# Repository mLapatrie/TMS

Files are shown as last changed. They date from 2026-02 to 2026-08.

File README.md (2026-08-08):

# Low-Cost Transcranial Magnetic Stimulation

Graphical Abstract

Code, hardware, and data for the paper ["Low-Cost Transcranial Magnetic Stimulation"](TODO) (PREPRINT, SUBJECT TO CHANGES), (2026).

This repository contains the design and validation materials for a low-cost monophasic transcranial magnetic stimulation (TMS) stimulator. As of July 2027, the bill of materials (BOM) runs at USD 657.34. The repository includes the electrical design, controller firmware, and terminal control interface, fabrication files, LTspice simulations, raw magnetic-field measurements, and analysis code to characterize the system.

> [!CAUTION]
> This system contains a high-energy capacitor bank and generates high voltages and strong, rapidly changing magnetic fields. Contact with the system can cause severe injury or death, and stored energy can remain after charging is halted.
> Never rely on the computer interface or firmware as the primary safety mechanism. Work must be performed by trained personnel.
> Do not connect this research prototype to a person or animal.

## Cite
If you use this code, hardware, or data in your research, please cite the following paper:

> **Low-Cost Transcranial Magnetic Stimulation**
> Maxence Lapatrie, Yuzuha Isetani, Jathav Puvirajan, Antonella Catanzaro, Siqi Lyu, Han C. Nguyen, William   Mathieu, Milica Popovich.
> TODO

TODO BIBTEX

## Contact
I welcome any feedback on the paper or repository. If you have questions or require help running the code, please do not hesitate to contact me.

**Email me** at maxence (dot) lapatrie (at) mail (dot) mcgill (dot) ca.<br>
Or message me on **LinkedIn** [maxence-lapatrie](https://www.linkedin.com/in/maxence-lapatrie/).

## System overview
The design separates the build into three voltage domains: control domain, power domain, and high voltage domain. The domains are isolated from each other. The Arduino lives in the control domain and sends signals to the other two domains to control charging and discharging.

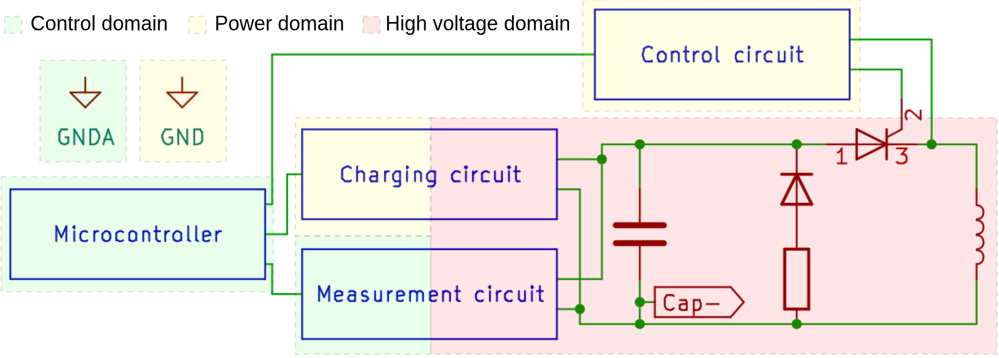
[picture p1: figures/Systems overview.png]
Systems Overview


See the complete [schematic](schematics/tms_schematic.pdf) for a more detailed understanding of the circuit.

## Repository contents
| Path | Contents |
| --- | --- |
| [`2d_models/`](2d_models/) | FreeCAD, SVG, PDF, and PNG fabrication drawings for the coil windings and busbars |
| [`3d_models/`](3d_models/) | FreeCAD sources and printable STL files for the coil winder and pickup coil helpers |
| [`controller_arduino/`](controller_arduino/) | Arduino UNO R4 Minima firmware and the Python terminal user interface |
| [`data_processing/`](data_processing/) | Raw oscilloscope captures, acquisition scripts, data analysis notebooks, SimNIBS helpers, and generated figures |
| [`figures/`](figures/) | Build, software-interface, and validation figures used in this README |
| [`schematics/`](schematics/) | KiCad project, hierarchical schematics, and a three-page PDF export |
| [`simulations/`](simulations/) | LTspice models for the charger, discharge path, gate driver, and IL300 linear optocoupler |
| [`Safety_Checklists.pdf`](Safety_Checklists.pdf) | Project-specific inspection, pre-charge, and de-energization checklists |
| [`TMS_field_grid.pdf`](TMS_field_grid.pdf) | Coordinate grids used for magnetic-field measurements |
| [`requirements.txt`](requirements.txt) | Pinned Python analysis environment |

Editable source files are included wherever possible. The PDF, SVG, STL, and PNG files are provided for convenience.

## Software setup

### Analysis environment

Python 3.10 or newer is recommended.
```bash
git clone <REPOSITORY_URL>
cd <REPOSITORY_DIRECTORY>

python3 -m venv .venv
source .venv/bin/activate
python -m pip install --upgrade pip
python -m pip install -r requirements.txt
```
Additional dependencies not included above:
- SimNIBS 4.6 is required by `data_processing/create_simple_figure_of_8_coil.py` and `data_processing/plot_simnibs.py`. Run these scripts in the Python environment supplied with the SimNIBS installation.
- KiCad, LTspice, and FreeCAD are recommended if one desires to edit the design files.

### Controller interface

Compile and upload [`controller_arduino.ino`](controller_arduino/controller_arduino.ino) to an Arduino UNO R4 Minima. Before compiling, review the pin assignments and calibrate the following firmware constants against the assembled measurement and gate-driver circuits:

- `MAX_ADC`: capacitor-bank overvoltage threshold in ADC counts;
- `FIRE_DELAY_US`: delay used to obtain the required SCR gate-pulse width;
- `COMP_STOP_ACTIVE`: active level of the independent comparator trip.

`MAX_ADC` must be calculated from measured values:

```text
MAX_ADC = round((V_trip / divider_ratio) / V_ref * ADC_FULL_SCALE)
```

The values committed in the firmware and terminal interface document the tested configuration; they are not universal safe defaults. The `DEFAULT_MAX_ADC` value in `app.py` must match the firmware `MAX_ADC`, and the divider ratio shown by the interface must match the physical divider tap in use.

```bash
cd controller_arduino
python app.py --divider <MEASURED_DIVIDER_RATIO> \
  --vref <MEASURED_ADC_REFERENCE_V> \
  --max-adc <FIRMWARE_MAX_ADC>
```

Press `p` in the interface to select a port.

| Key | Command |
| --- | --- |
| `r` | Reset the controller state after all hardware trips are clear |
| `c` | Start or stop charging |
| `a` | Arm or unarm the discharge; arming also stops charging |
| `f` | Request one firing pulse while armed |
| `s` | Query controller status |
| `p` | Select a serial port |
| `d` | Disconnect |
| `q` | Quit |

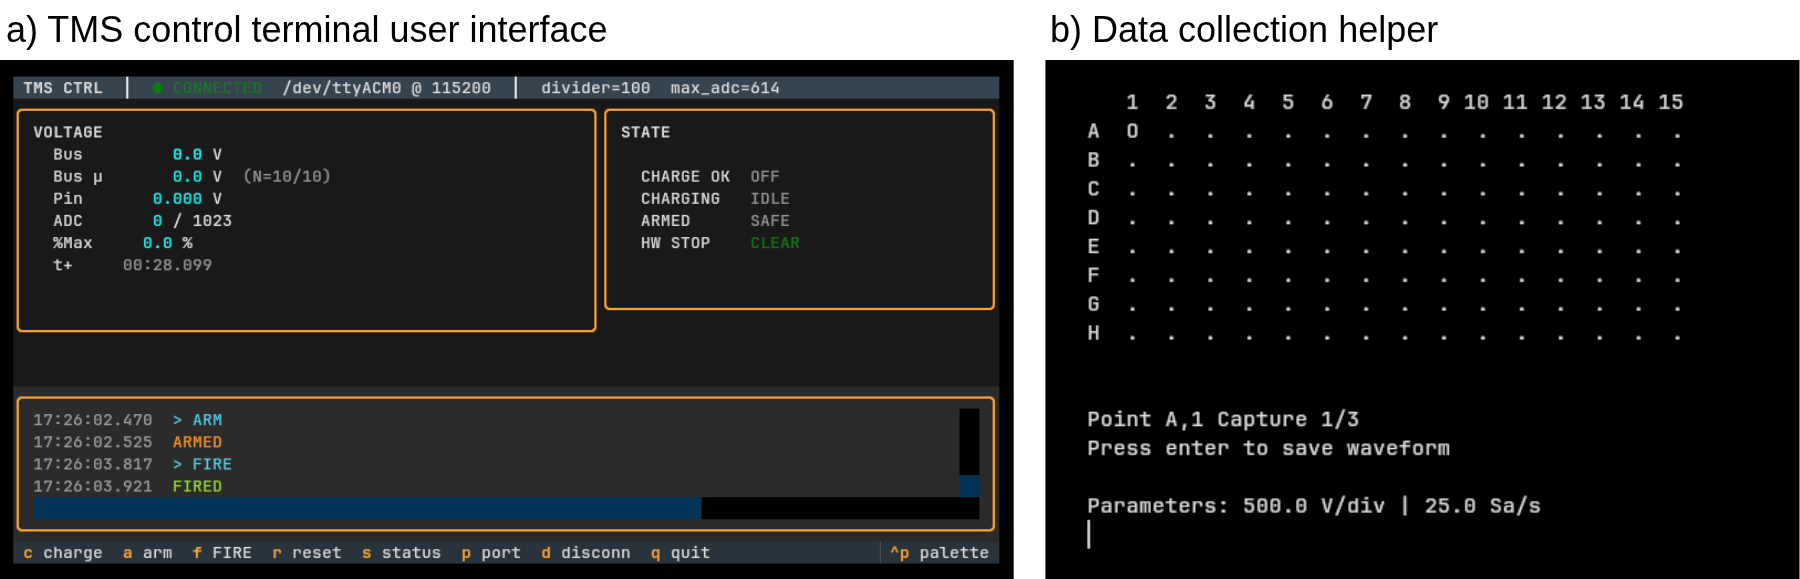
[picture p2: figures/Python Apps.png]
Controller interface and data-collection helper


## Data collection and analysis

The data used in our analyses is provided under [`data_processing/waveforms`](data_processing/waveforms). The MagVenture* components correspond to the data collected from the MRI-B91 MagVenture coil with the MagVenture MagPro X100 TMS. The other components correspond to the homemade coil under 24V and 1480V capacitor charges.

### Magnetic-field grid acquisition

[`collect_grid.py`](data_processing/collect_grid.py) automates oscilloscope captures at each location of a pre-programmed field-measurement grid. Before use:

1. Replace the VISA resource string with the identifier reported for the oscilloscope;
2. Select the measured field component;
3. Set `start_row` and `start_col` if resuming an interrupted acquisition; and
4. Confirm the oscilloscope channel, vertical scale, offset, sample rate, and binary-waveform format.

Each capture is stored as a CSV file with `Time (s)` and `Voltage (V)` columns.
Use [`TMS_field_grid.pdf`](TMS_field_grid.pdf) to help position your pickup coil.

### Deriving coil change of current

[`derive_didt.ipynb`](data_processing/derive_didt.ipynb):
1. Loads capacitor and three-axis pickup-coil waveforms;
2. Filters and maps the measured peak voltages;
3. Converts the measurements to empirical dB/dt maps;
4. Computes corresponding maps from a discretized figure-of-eight coil model; and
5. Estimates coil dI/dt by a global least-squares fit.

Change `user_local_dir` at the beginning of the notebook before running it. Select `homemade_coil` and `low_voltage` to match the dataset being analyzed.

### Other data analysis helpers

- [`plot_gate_pulses.ipynb`](data_processing/plot_gate_pulses.ipynb) compares the microcontroller and gate-resistor pulses and estimates the gate-current rise rate. It expects local files under `waveforms/gate_component/`.
- [`create_fo8_coil.py`](data_processing/create_fo8_coil.py) creates the line-segment TMS coil model used by SimNIBS.

## Example validation output

The repository includes raw low-voltage, high-voltage, and commercial-coil reference measurements. The figure below compares the measured and wire-segment-model dB/dt maps and shows the global least-squares fits used to estimate coil dI/dt at low and high capacitor-bank voltages:

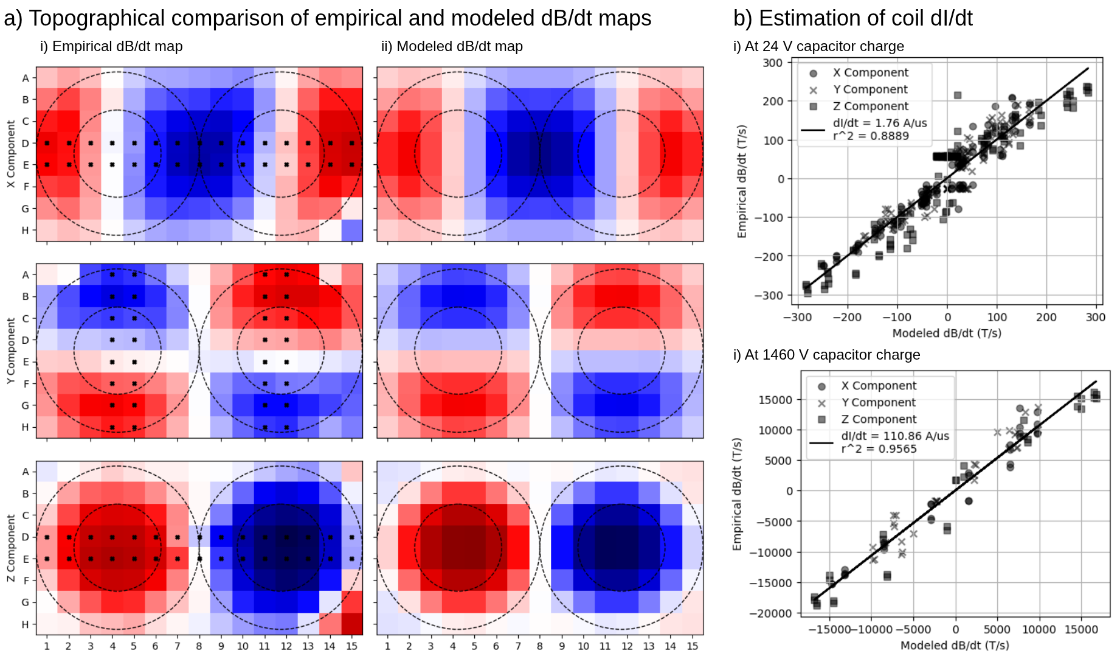
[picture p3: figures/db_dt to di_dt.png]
Empirical and modeled dB/dt maps with estimated coil dI/dt


## Safety documentation

Read [`Safety_Checklists.pdf`](Safety_Checklists.pdf) before inspecting or operating the physical system. These checklists document the procedures used for this prototype, but they are not a substitute for a complete, site-specific risk assessment or formal training.

## Licensing

The controller source files, data analysis code, and data collection code are licensed under the MIT SPDX license. The SimNIBS-derived coil-generation example retains its GPLv3 notice. All hardware files are licensed under the CERN-OHL-P-2.0 license. Project-authored data, figures, and documentation are licensed under the CC-BY-4.0 license. Read [LICENSE](LICENSE) for more information.

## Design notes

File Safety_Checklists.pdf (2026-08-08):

Safety Checklists

Device inspection

□ Bank voltage reads 0 V on the connected multimeter.

□ Busbars show no cracking along the flattened edges and have no loosened joints.

□ Nothing is touching the busbars except at the intended connection sites.

□ Bleeders and voltage divider resistors are visually intact and connected at their respective terminals.

□ Safety discharge stick is connected to the bank-negative busbar through discharge resistors and is within reach.

□ Correct transformer tap is selected for the target voltage.

□ Transformer taps are far away from each other.

□ Target voltage does not exceed the system’s maximum voltage.

□ Enclosure lid is closed; lid interlock closed.

□ Dead-man interlock is held by the second person.

□ Comparator trip threshold is set for the intended voltage.

□ Multimeter is readable and enclosed with the high voltage circuitry.

□ PSU current limit set according to expected maximum current draw.

□ TUI divider ratio matches the divider tap actually in use.

□ TUI shows a nominal state. Press R to reset if needed.

Pre-charge safety checklist

□ At least two people are present. Both have been briefed on the location and operation of the charge-cutoff switch, the discharge stick, and the de-energization checklist.

□ Operator is wearing Class 1 insulating rubber gloves and insulated footwear. Every person present is wearing impact-rated eye protection.

□ No rings, watches, or other conductive materials on either person.

□ Bench is clear of conductive clutter, tools, and stray wires.

□ No liquids on or near the setup.

□ A physical barrier separates the operator from the high-voltage components.

□ Both people are clear of the high-voltage region and ready for the circuit to be energized.

1

De-energization

□ Stop charging by pressing C again or pressing A to arm the system. The current draw should drop to quiescent levels.

□ Cut the PSU feed either by releasing the dead-man interlock or by pressing the charge-cutoff switch.

□ Turn the PSU off with its respective on/off switch, or by disconnecting the PSU directly from the wall.

□ Verify the multimeter is reading a non-zero voltage. Be wary of zero voltage readings as the multimeter might have been disconnected from the circuit or might be malfunctioning.

□ Allow the bleeders to drain the bank (leave untouched for at least 20 minutes), or

□ Make firm, quick contact with the safety discharge stick hook on the bank positive terminal through the enclosure port. Hold contact for at least 5 seconds.

□ Verify the multimeter reads a bank voltage of 0 V. Verify the multimeter probes are connected to the bank.

□ If the probes of the multimeter appear disconnected, connect the discharge stick for another 10 seconds and leave the device untouched for at least 20 minutes.

2

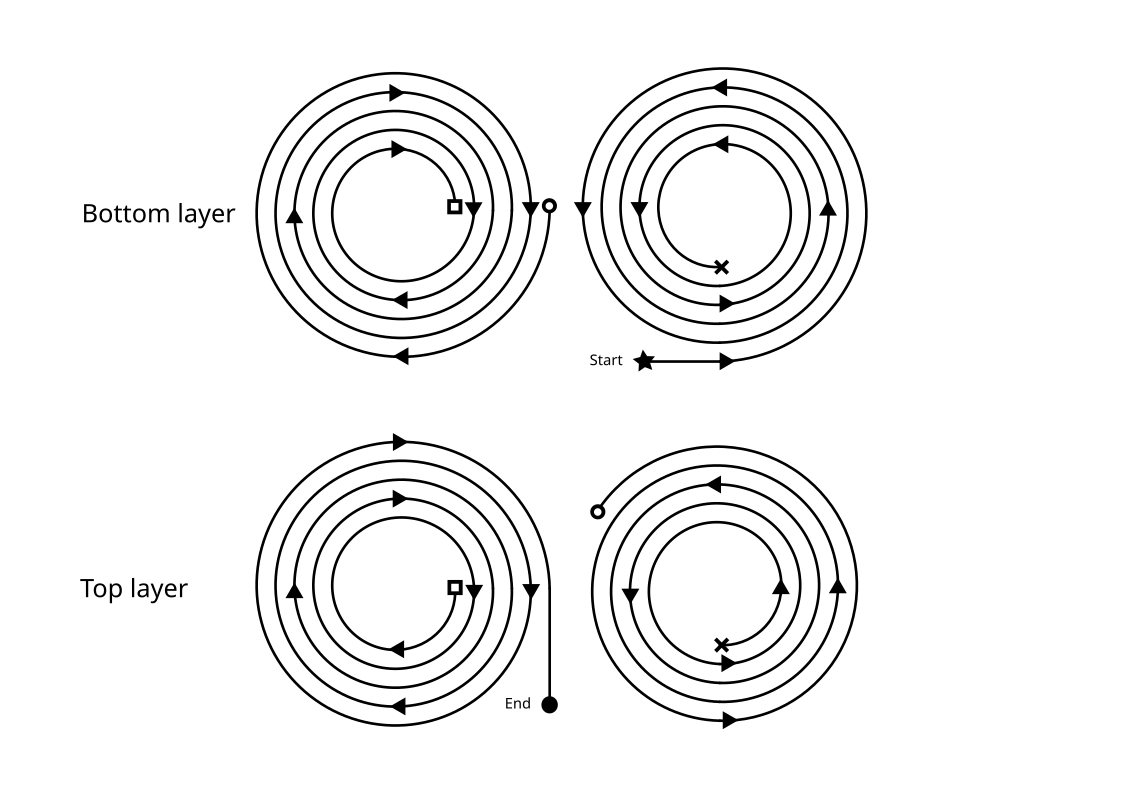
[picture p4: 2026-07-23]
2d_models/coil_windings/coil_windings.png

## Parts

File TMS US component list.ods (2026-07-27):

Designator | Component | Description | Qty | Cost Per Unit (USD) | Total Cost (USD) | Source of Materials | Material Type
Discharge Circuit: C1, C2 | C44UQGT6460T86K | Main discharge capacitors 460uF each | 2 | $110.56 | $221.12 | https://www.digikey.com/en/products/detail/kemet/C44UQGT6460T86K/18734476 | Metal
Discharge Circuit: R1, R2, R3, R4, R5, R6 | FMP200JT-52-220K | Bleed resistors 220k 2W | 6 | $0.20 | $1.20 | https://www.digikey.com/en/products/detail/yageo/FMP200JT-52-220K/9110366 | Metal
Discharge Circuit: D1,Q1 | MCMA260PD1800YB | SCR Module | 1 | $119.78 | $119.78 | https://www.digikey.com/en/products/detail/ixys/MCMA260PD1800YB/11304802 | Composite
Discharge Circuit: R7 | Dampening resistor | 1/8" (3MM) Wire Rope, 100FT Stainless Steel Cable | 1 | $16.99 | $16.99 | https://www.amazon.com/Antrader-Stainless-Crimping-Sleeves-Projects/dp/B0FQ4ZB6FR | Metal
Discharge Circuit | Busbar wiring | Copper Pipe Type M 3/4-inch x 5 Foot Straight Length | 1 | $26.81 | $26.81 | https://www.homedepot.com/p/Mueller-Streamline-3-4-in-x-5-ft-Copper-Type-M-Pipe-MH06005/100346419 | Metal
Discharge Circuit | Busbar isolation | Kapton tape | 1 | $2.50 | $2.50 | https://www.amazon.com/ELEGOO-Polyimide-Temperature-Resistant-Multi-Sized/dp/B072Z92QZ2 | Polymer
Discharge Circuit: R18 | 1MOhm 1/4W resistor | Voltage divider high side resistors | 10 | $0.10 | $1.00 | https://www.digikey.com/en/products/detail/stackpole-electronics-inc/CF14JT1M00/1741316 | Ceramic
Discharge Circuit: R19 | 22kOhm 1/4 resistor | Voltage divider low side resistor | 1 | $0.10 | $0.10 | https://www.digikey.com/en/products/detail/stackpole-electronics-inc/CFM14JT22K0/1742143 | Ceramic
Discharge Circuit: R19 | 3kOhm 1/4 resisotr | Voltage divider low side resistor | 1 | $0.10 | $0.10 | https://www.digikey.com/en/products/detail/stackpole-electronics-inc/CF14JT3K00/1741418 | Ceramic
Discharge Circuit: L1 | Coil wire | 10 AWG Stranded copper wire (25ft) | 1 | $14.99 | $14.99 | https://www.amazon.com/Translucent-Primary-Automotive-Lightning-Electrical/dp/B0CZ6QFZ67 | Metal
Discharge Circuit | Wire insulation | Kapton tape | 1 | $2.50 | $2.50 | https://www.amazon.com/ELEGOO-Polyimide-Temperature-Resistant-Multi-Sized/dp/B072Z92QZ2 | Polymer
Discharge Circuit | Coil insulation | Electric tape | 1 | $3.78 | $3.78 | https://www.amazon.com/Scotch-Electrical-Tape-4-Inch-66-Foot/dp/B001ULCB1O | Polymer
Discharge Circuit | Coil winder filament | 85g of PLA filament. 1kg for 20.39 cad. 1kg for 13.99 usd. | 1 | $1.19 | $1.19 | https://www.amazon.com/Printer-Filament-SUNLU-Dimensional-Accuracy/dp/B07XG3RM58 | Polymer
Discharge Circuit: SW1 | On/Off Switch | DC On/Off switch for PSU | 1 | $14.44 | $14.44 | https://www.digikey.com/en/products/detail/nkk-switches/JWMW21RC1A/2104374 | Composite
Discharge Circuit: SW2, SW3 | Contact switches (microwave door switches) | Interlock switches | 2 | $2.97 | $5.94 | https://www.amazon.com/Microwave-Switch-Interloc-Normally-Close/dp/B07XZFNPZM | Composite
Discharge Circuit: R8, R9 | 50W 1kOhm discharge resistor | Safety stick discharge resistors | 2 | $5.99 | $11.98 | https://www.digikey.com/en/products/detail/stackpole-electronics-inc/KAL50FB1K00/1646209 | Ceramic
Discharge Circuit | PVC pipe | PEX-B pipe for safety stick | 1 | $3.22 | $3.22 | https://www.homedepot.com/p/Apollo-1-2-in-x-5-ft-White-PEX-B-Pipe-APPW512/301541214 | Polymer
Discharge Circuit | 18 AWG HV silicone wire | Safety stick cable (5ft) | 5 | $1.41 | $7.05 | https://www.digikey.com/en/products/detail/cnc-tech/3239-18-1-0500-001-1-TS/3766986 | Polymer
Gate Driver Circuit: U12 | TC4420CPA | MOSFET gate driver | 1 | $2.02 | $2.02 | https://www.digikey.com/en/products/detail/microchip-technology/TC4420CPA/267369 | Composite
Gate Driver Circuit | A 08-LC-TT | 8 pin IC socket (optional) | 5 | $0.67 | $3.35 | https://www.digikey.com/en/products/detail/assmann-wsw-components/A-08-LC-TT/821740 | Composite
Gate Driver Circuit: C14 | 0.1 uF ceramic capacitor | Fast energy bank for the pulse | 1 | $0.24 | $0.24 | https://www.digikey.com/en/products/detail/tdk/FG18X7R1H104KNT06/5802879 | Ceramic
Gate Driver Circuit: C15 | 100 uF electrolytic capacitor | Slow energy bank for the pulse | 1 | $0.53 | $0.53 | https://www.digikey.com/en/products/detail/rubycon/50ZLJ100MT78X11-5/3134619 | Metal
Gate Driver Circuit: T2 | P0584NL | 1:1 Pulse Transformer | 1 | $4.77 | $4.77 | https://www.digikey.com/en/products/detail/pulse-electronics/P0584NL/2264931 | Composite
Gate Driver Circuit: D19, D20, D21, D22 | 1n5819 | Schottky Diodes | 4 | $0.29 | $1.16 | https://www.digikey.com/en/products/detail/diotec-semiconductor/1N5819/13164178 | Semiconductor
Gate Driver Circuit: R30 | 10 Ohm gate resistor | 10 Ohm gate resistor | 1 | $0.10 | $0.10 | https://www.digikey.com/en/products/detail/stackpole-electronics-inc/RNF14FTD10R0/1709720 | Ceramic
Gate Driver Circuit | 22 AWG wire | Wire for the whole circuit (1 m) | 1 | $0.30 | $0.30 | https://www.amazon.com/TUOFENG-Hookup-Wires-6-Different-Colored/dp/B07TX6BX47 | Metal
Gate Driver Circuit: U11 | VO2611 | HV Pulse Optocoupler | 1 | $2.25 | $2.25 | https://www.digikey.com/en/products/detail/vishay-semiconductor-opto-division/VO2611/1738647 | Composite
Gate Driver Circuit: R28 | 620 Ohm 1/4W resistor | 620 Ohm resistor for optocoupler LV side | 1 | $0.10 | $0.10 | https://www.digikey.com/en/products/detail/stackpole-electronics-inc/CF14JT620R/1741482 | Ceramic
Gate Driver Circuit: R29 | 1.2k Ohm 1/4W resistor | 1.2k Ohm resistor for optocoupler HV side | 1 | $0.10 | $0.10 | https://www.digikey.com/en/products/detail/stackpole-electronics-inc/CF14JT1K20/1741238 | Ceramic
Gate Driver Circuit: C13 | 0.1 uF optocoupler capacitor | 0.1 uF capacitor for optocoupler HV side | 1 | $0.24 | $0.24 | https://www.digikey.com/en/products/detail/tdk/FG18X7R1H104KNT06/5802879 | Ceramic
Charging Circuit: U1 | L7812CV | Linear voltage regulator | 1 | $1.17 | $1.17 | https://www.digikey.com/en/products/detail/stmicroelectronics/L7812CV/585973 | Composite
Charging Circuit: U2 | L7805CV | Linear voltage regulator | 1 | $1.05 | $1.05 | https://www.digikey.com/en/products/detail/stmicroelectronics/L7805CV/585964 | Composite
Charging Circuit: C5, C6 | 0.33 uF ceramic capacitor | Supports the voltage regulators | 2 | $0.32 | $0.64 | https://www.digikey.com/en/products/detail/tdk/FG24X7R1H334KNT06/5802993 | Ceramic
Charging Circuit: C7, C8 | 0.1 uF ceramic capacitor | Supports the voltage regulators | 2 | $0.24 | $0.48 | https://www.digikey.com/en/products/detail/tdk/FG18X7R1H104KNT06/5802879 | Ceramic
Charging Circuit: A1 | Arduino UNO R4 | Arduino | 1 | $20.00 | $20.00 | https://www.digikey.com/en/products/detail/arduino/ABX00080/20371542 | Composite
Charging Circuit: K1 | AZ9861-1C-24DC2R1 | 24 VDC relay | 1 | $5.66 | $5.66 | https://www.digikey.com/en/products/detail/american-zettler/AZ9861-1C-24DC2R1/18339576 | Composite
Charging Circuit: D2 | 1n5819 | Schottky Diode | 1 | $0.29 | $0.29 | https://www.digikey.com/en/products/detail/diotec-semiconductor/1N5819/13164178 | Semiconductor
Charging Circuit: C9 | 1189-1397-ND | 4700uF 50V capacitor | 1 | $3.50 | $3.50 | https://www.digikey.com/en/products/detail/rubycon/50PK4700MEFC18X40/3134353 | Metal
Charging Circuit: ZVS Driver | ZVS Driver | ZVS Driver | 1 | $15.99 | $15.99 | https://www.amazon.com/FainWan-Voltage-Inductor-Generator-DC12-30V/dp/B0BV6GYNK8 | Composite
Charging Circuit: T1 | ETD49/25/16-3C94 | Transformer Cores | 2 | $3.93 | $7.86 | https://www.digikey.com/en/products/detail/ferroxcube/ETD49-25-16-3C94/7041568 | Ceramic
Charging Circuit: T1 | B66368W1020T001 | Transformer Bobbin | 1 | $4.14 | $4.14 | https://www.digikey.com/en/products/detail/epcos-tdk-electronics/B66368W1020T001/3914849 | Polymer
Charging Circuit: T1 | B66368A2000X000 | Transformer Clips | 2 | $0.80 | $1.60 | https://www.digikey.com/en/products/detail/epcos-tdk-electronics/B66368A2000X000/3915618 | Metal
Charging Circuit: D3, D4, D5, D6, D7, D8, D9, D10, D11, D12, D13, D14, D15, D16, D17, D18 | UF4007 | HV Diode | 16 | $0.50 | $8.00 | https://www.digikey.com/en/products/detail/onsemi/UF4007/965478 | Semiconductor
Charging Circuit: R16, R17 | 1kOhm 25W | Resistor | 2 | $5.22 | $10.44 | https://www.digikey.com/en/products/detail/stackpole-electronics-inc/KAL25FB1K00/1646190 | Ceramic
Charging Circuit: U8A | LM393N/NOPB | Voltage Comparator | 1 | $0.92 | $0.92 | https://www.digikey.com/en/products/detail/texas-instruments/LM393N-NOPB/9526 | Composite
Charging Circuit: RV1 | 5kOhm potentiometer | Comparator voltage divider potentiometer | 1 | $5.35 | $5.35 | https://www.digikey.com/en/products/detail/cts-electrocomponents/026TB32R502B1A1/203779 | Composite
Charging Circuit: R23 | 5.6kOhm resistor | Comparator voltage divider resistor | 1 | $0.10 | $0.10 | https://www.digikey.com/en/products/detail/stackpole-electronics-inc/CFM14JT5K60/1742235 | Ceramic
Charging Circuit: R24 | 1MOhm resistor | Hysteresis resistor | 1 | $0.10 | $0.10 | https://www.digikey.com/en/products/detail/stackpole-electronics-inc/CF14JT1M00/1741316 | Ceramic
Charging Circuit: R25 | 10kOhm resistor | Comparator pull up resistor | 1 | $0.10 | $0.10 | https://www.digikey.com/en/products/detail/stackpole-electronics-inc/CF14JT10K0/1741265 | Ceramic
Charging Circuit: BT1 | 9V battery | Comparator battery | 1 | $1.59 | $1.59 | https://www.amazon.com/Amazon-Basics-Performance-All-Purpose-Batteries/dp/B00MH4QM1S | Metal
Charging Circuit: U3, U4, U9 | VO2611 | HV Pulse Optocoupler | 3 | $2.25 | $6.75 | https://www.digikey.com/en/products/detail/vishay-semiconductor-opto-division/VO2611/1738647 | Composite
Charging Circuit: R10, R13, R27 | 620 Ohm 1/4W resistor | 620 Ohm resistor for optocoupler LV side | 3 | $0.10 | $0.30 | https://www.digikey.com/en/products/detail/stackpole-electronics-inc/CF14JT620R/1741482 | Ceramic
Charging Circuit: R11 | 1.2k Ohm 1/4W resistor | 1.2k Ohm resistor for optocoupler HV side | 1 | $0.10 | $0.10 | https://www.digikey.com/en/products/detail/stackpole-electronics-inc/CF14JT1K20/1741238 | Ceramic
Charging Circuit: R26 | 1.2k Ohm 1/4W resistor | 1.2k Ohm resistor for optocoupler LV side | 1 | $0.10 | $0.10 | https://www.digikey.com/en/products/detail/stackpole-electronics-inc/CF14JT1K20/1741238 | Ceramic
Charging Circuit: C10, C12, C14 | 0.1 uF optocoupler capacitor | 0.1 uF capacitor for optocoupler HV side | 3 | $0.24 | $0.72 | https://www.digikey.com/en/products/detail/tdk/FG18X7R1H104KNT06/5802879 | Ceramic
Charging Circuit: C11, C13, C15 | 22 pF optocoupler capacitor | 22 pF capacitor for optocoupler HV side | 3 | $0.30 | $0.90 | https://www.digikey.com/en/products/detail/tdk/FA18NP01H220JNU06/5865955 | Ceramic
Charging Circuit: Q2, Q3 | BC337 NPN Transistor | NPN for relay coil control | 2 | $0.18 | $0.36 | https://www.digikey.com/en/products/detail/diotec-semiconductor/BC337-25/13164719 | Semiconductor
Charging Circuit: R12, R14 | 1.5kOhm 1/4W resistor | Base resistor for NPN | 2 | $0.10 | $0.20 | https://www.digikey.com/en/products/detail/yageo/CFR-25JB-52-1K5/132 | Ceramic
Charging Circuit: R3 | 10kOhm 1/4W resistor | Pull down NPN resistor | 1 | $0.10 | $0.10 | https://www.digikey.com/en/products/detail/stackpole-electronics-inc/CF14JT10K0/1741265 | Ceramic
Charging Circuit | 16 AWG wire | PSU to ZVS wiring | 1 | $3.33 | $3.33 | https://www.amazon.com/NAOEVO-Silicone-Electrical-Breadboard-Automotive/dp/B0CMLFRQDQ | Metal
Charging Circuit | 28 AWG enameled wire | Primary and secondary wiring (530 ft) | 1 | $11.99 | $11.99 | https://www.amazon.com/BNTECHGO-AWG-Magnet-Wire-Transformers/dp/B07DYF53ZN | Metal
Charging Circuit | 18 AWG HV silicone wire | Full bridge to capacitor wiring (1ft) | 1 | $1.41 | $1.41 | https://www.digikey.com/en/products/detail/cnc-tech/3239-18-1-0500-001-1-TS/3766986 | Polymer
Charging Circuit | 22 AWG wire | Wire for LV circuit boards (1 m) | 1 | $0.30 | $0.30 | https://www.amazon.com/TUOFENG-Hookup-Wires-6-Different-Colored/dp/B07TX6BX47 | Metal
Charging Circuit: U6 | IL300 | Linear Optocoupler | 1 | $3.81 | $3.81 | https://www.digikey.com/en/products/detail/vishay-semiconductor-opto-division/IL300/1731525 | Composite
Charging Circuit: U5, U7, U1 | UA741 | Op amp for linear optocoupler | 3 | $0.64 | $1.92 | https://www.digikey.com/en/products/detail/texas-instruments/UA741CP/382197 | Composite
Charging Circuit: R20, R22 | 100kOhm resistor | 100kOhm gain resistors for linear optocoupler | 2 | $0.10 | $0.20 | https://www.digikey.com/en/products/detail/stackpole-electronics-inc/CF14JT100K/1741263 | Ceramic
Charging Circuit: R21 | 1kOhm resistor | 1kOhm servo resistor | 1 | $0.10 | $0.10 | https://www.digikey.com/en/products/detail/stackpole-electronics-inc/CF14JT1K00/1741314 | Ceramic
Charging Circuit: U8A | LM358 | Op amp for voltage follower | 2 | $0.30 | $0.60 | https://www.digikey.com/en/products/detail/texas-instruments/LM358P/277042 | Composite
Charging Circuit | Dupont wires MM | Wires to arduino | 20 | $0.06 | $1.20 | https://www.amazon.com/Elegoo-EL-CP-004-Multicolored-Breadboard-arduino/dp/B01EV70C78 | Metal
Sensing | 28 AWG wire | Pick up coil (2ft), included in the transformer winding wire | 1 | $0.50 | $0.50 | https://www.amazon.com/BNTECHGO-AWG-Magnet-Wire-Transformers/dp/B07DYF53ZN | Metal
Sensing | PLA filament | PLA for winding cylinder (2g) | 1 | $0.05 | $0.05 | https://www.amazon.com/Printer-Filament-SUNLU-Dimensional-Accuracy/dp/B07XG3RM58 | Polymer
Sensing | 100x P4250 Probe | 100x oscilloscope probe with 2000Vpp rating | 1 | $22.99 | $22.99 | https://www.amazon.com/Goupchn-Voltage-Oscilloscope-Probe-P4250/dp/B086V9B67C | Composite
Sensing | PLA filament | PLA for sensing cross (6g) | 1 | $0.15 | $0.15 | https://www.amazon.com/Printer-Filament-SUNLU-Dimensional-Accuracy/dp/B07XG3RM58 | Polymer
Misc | Perforated boards |  | 6 | $0.25 | $1.50 | https://www.amazon.com/Rindion-Compatible-Prototype-Electronics-Soldering/dp/B0DBZ1BXFZ | Composite
Misc | M6 bolts |  | 2 | $2.97 | $5.94 | https://www.homedepot.com/p/M6-1-0x16mm-Stainless-Steel-Pan-Head-Phillips-Drive-Machine-Screw-1-Piece-863568/323368376 | Metal
Misc | M6 nuts |  | 2 | $3.97 | $7.94 | https://www.homedepot.com/p/Everbilt-M6-1-0-Zinc-Hex-Nut-5-Pieces-860728/323371196 | Metal
Misc | M6 washers | Large washers | 2 | $0.21 | $0.42 | https://www.homedepot.com/p/Everbilt-1-4-in-x-1-1-4-in-Zinc-Plated-Fender-Washer-804796/204632767 | Metal
Misc | Encasing | 50L container | 1 | $20.98 | $20.98 | https://www.homedepot.com/p/Sterilite-70-Qt-Ultra-Storage-Box-19888604/204606576 | Polymer
Misc | Zipties |  | 1 | $3.99 | $3.99 | https://www.amazon.com/Tensile-Strength-indoor-outdoor-Skalon/dp/B09PJ8L58G | Polymer
 |  |  |  | Total (USD, before tax) | $657.68

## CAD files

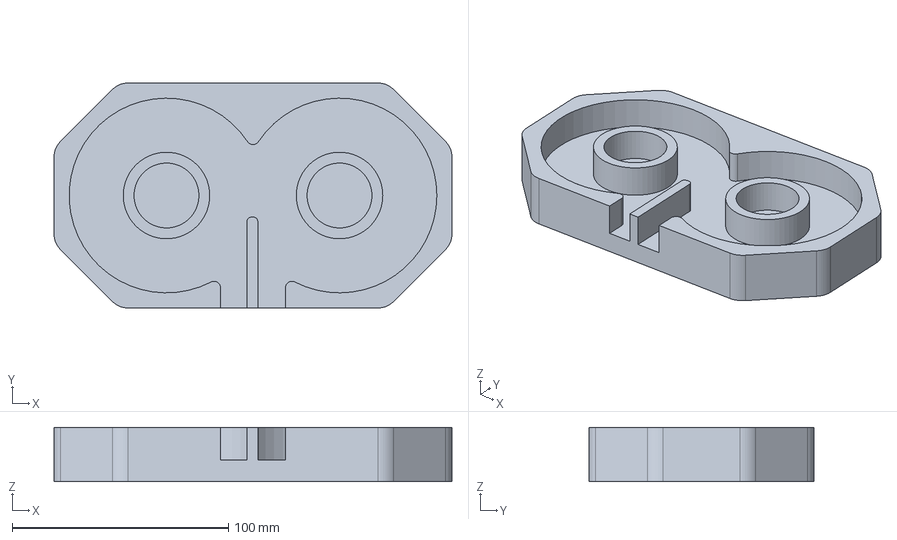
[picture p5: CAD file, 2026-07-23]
3d_models/coil_winder/coil_winder.FCStd
184.0 x 104.0 x 25.0 mm

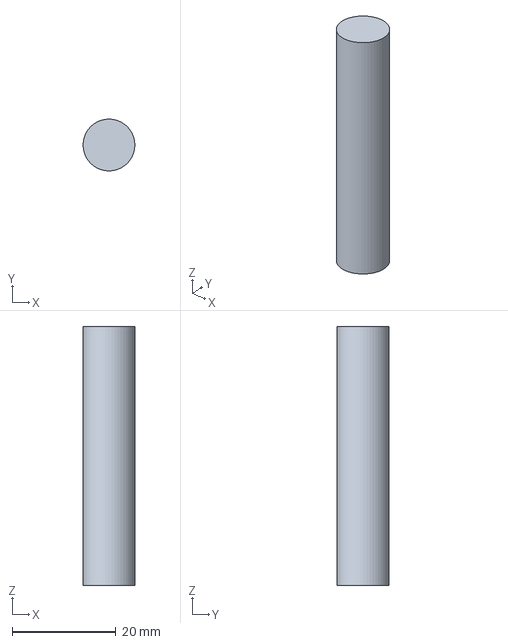
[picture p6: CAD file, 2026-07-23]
3d_models/pickup_cylinder/pickup_cylinder.FCStd
9.99 x 10.00 x 50.0 mm

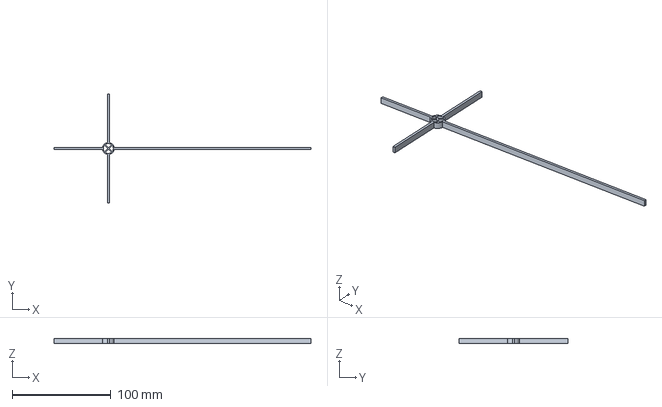
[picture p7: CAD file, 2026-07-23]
3d_models/sensing_cross/sensing_cross.FCStd
260.0 x 110.0 x 5.00 mm

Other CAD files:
2d_models/busbars/busbars.FCStd
2d_models/coil_windings/coil_windings.FCStd
3d_models/coil_winder/coil_winder.stl
3d_models/pickup_cylinder/pickup_cylinder.stl
3d_models/sensing_cross/sensing_cross.stl

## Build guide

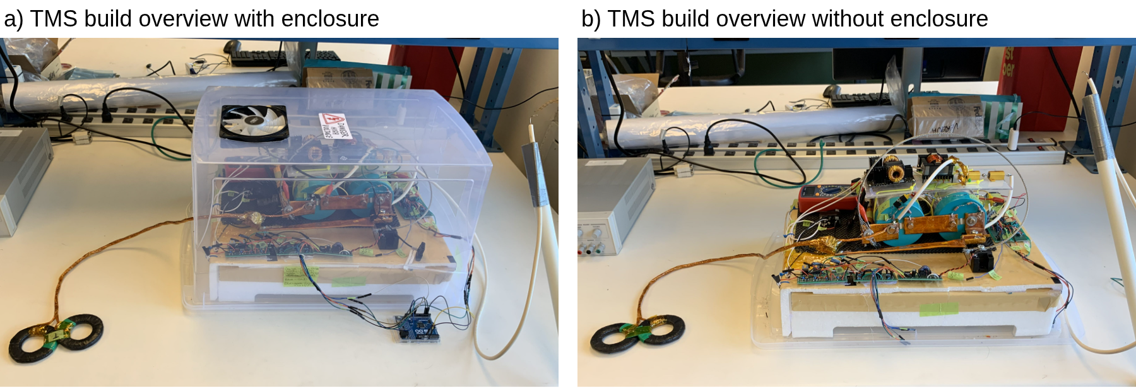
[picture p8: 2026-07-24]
figures/TMS build overview.png

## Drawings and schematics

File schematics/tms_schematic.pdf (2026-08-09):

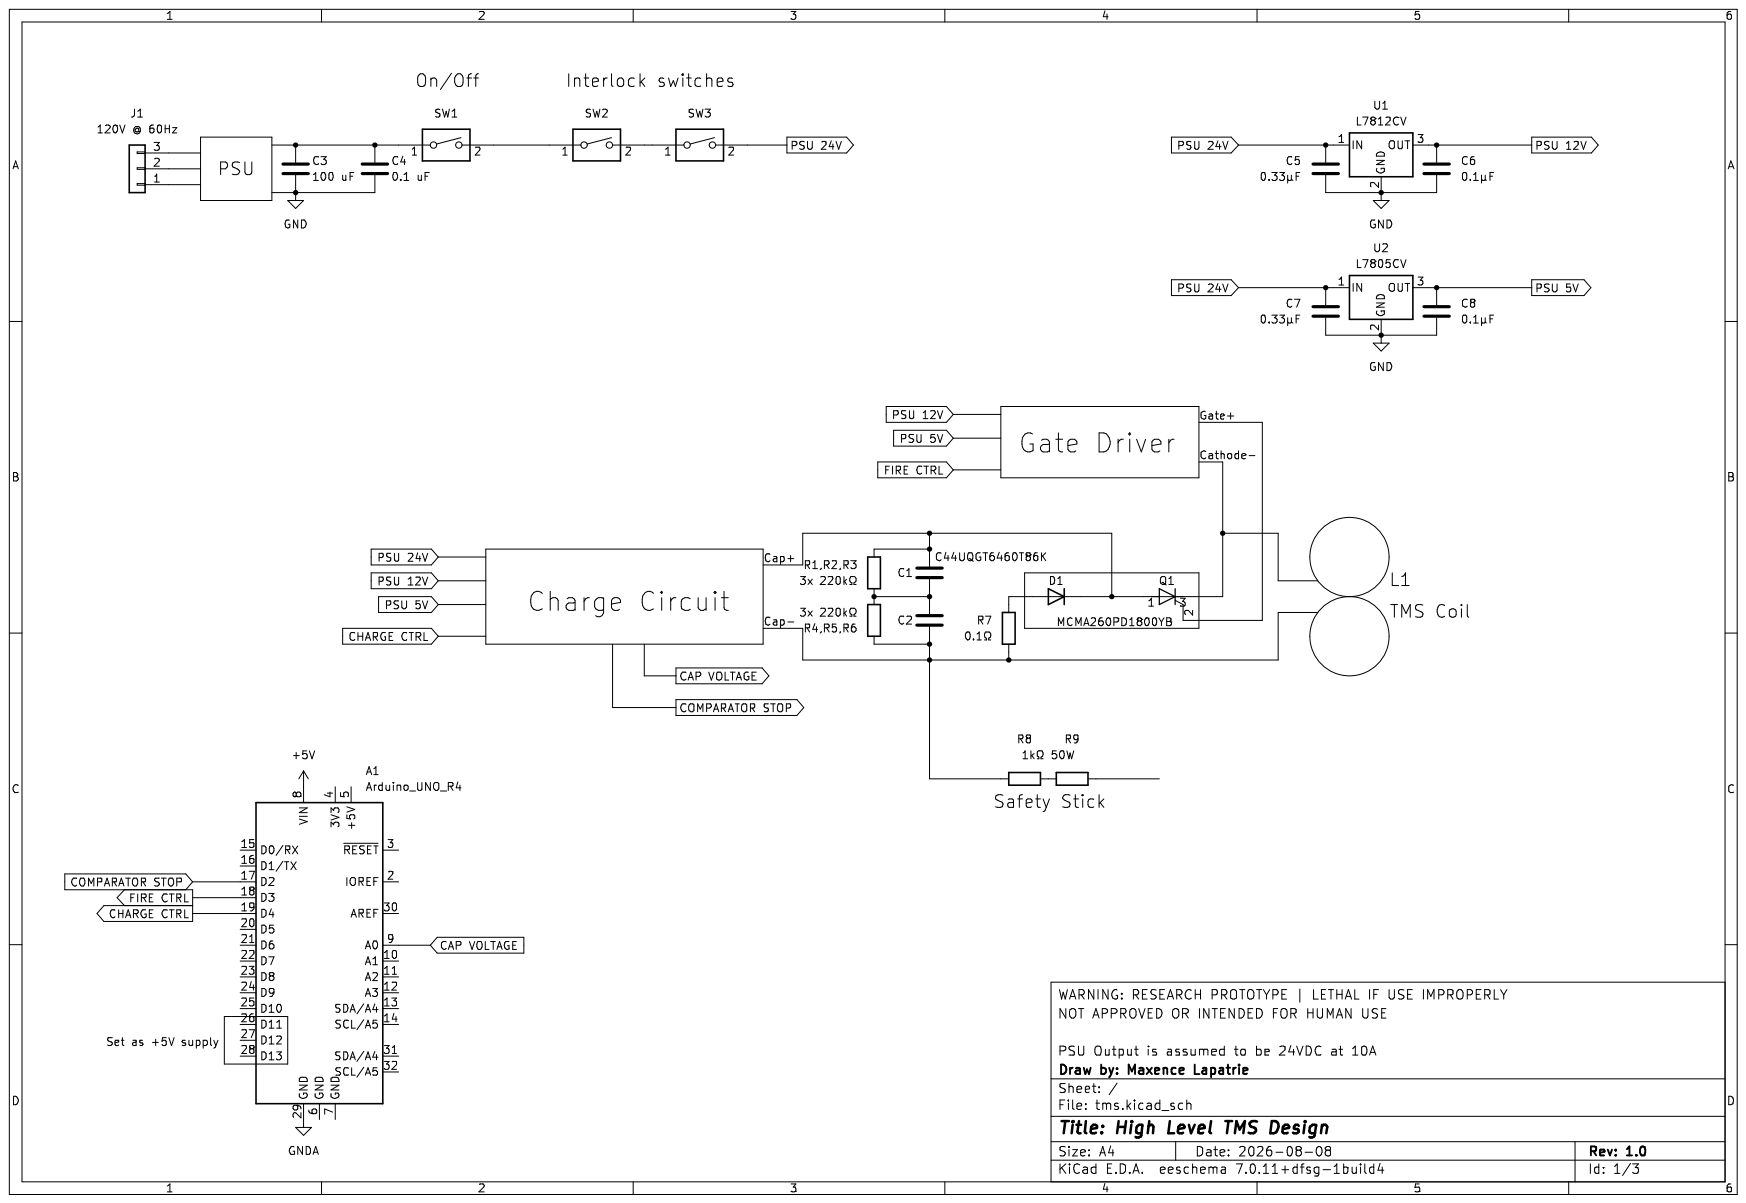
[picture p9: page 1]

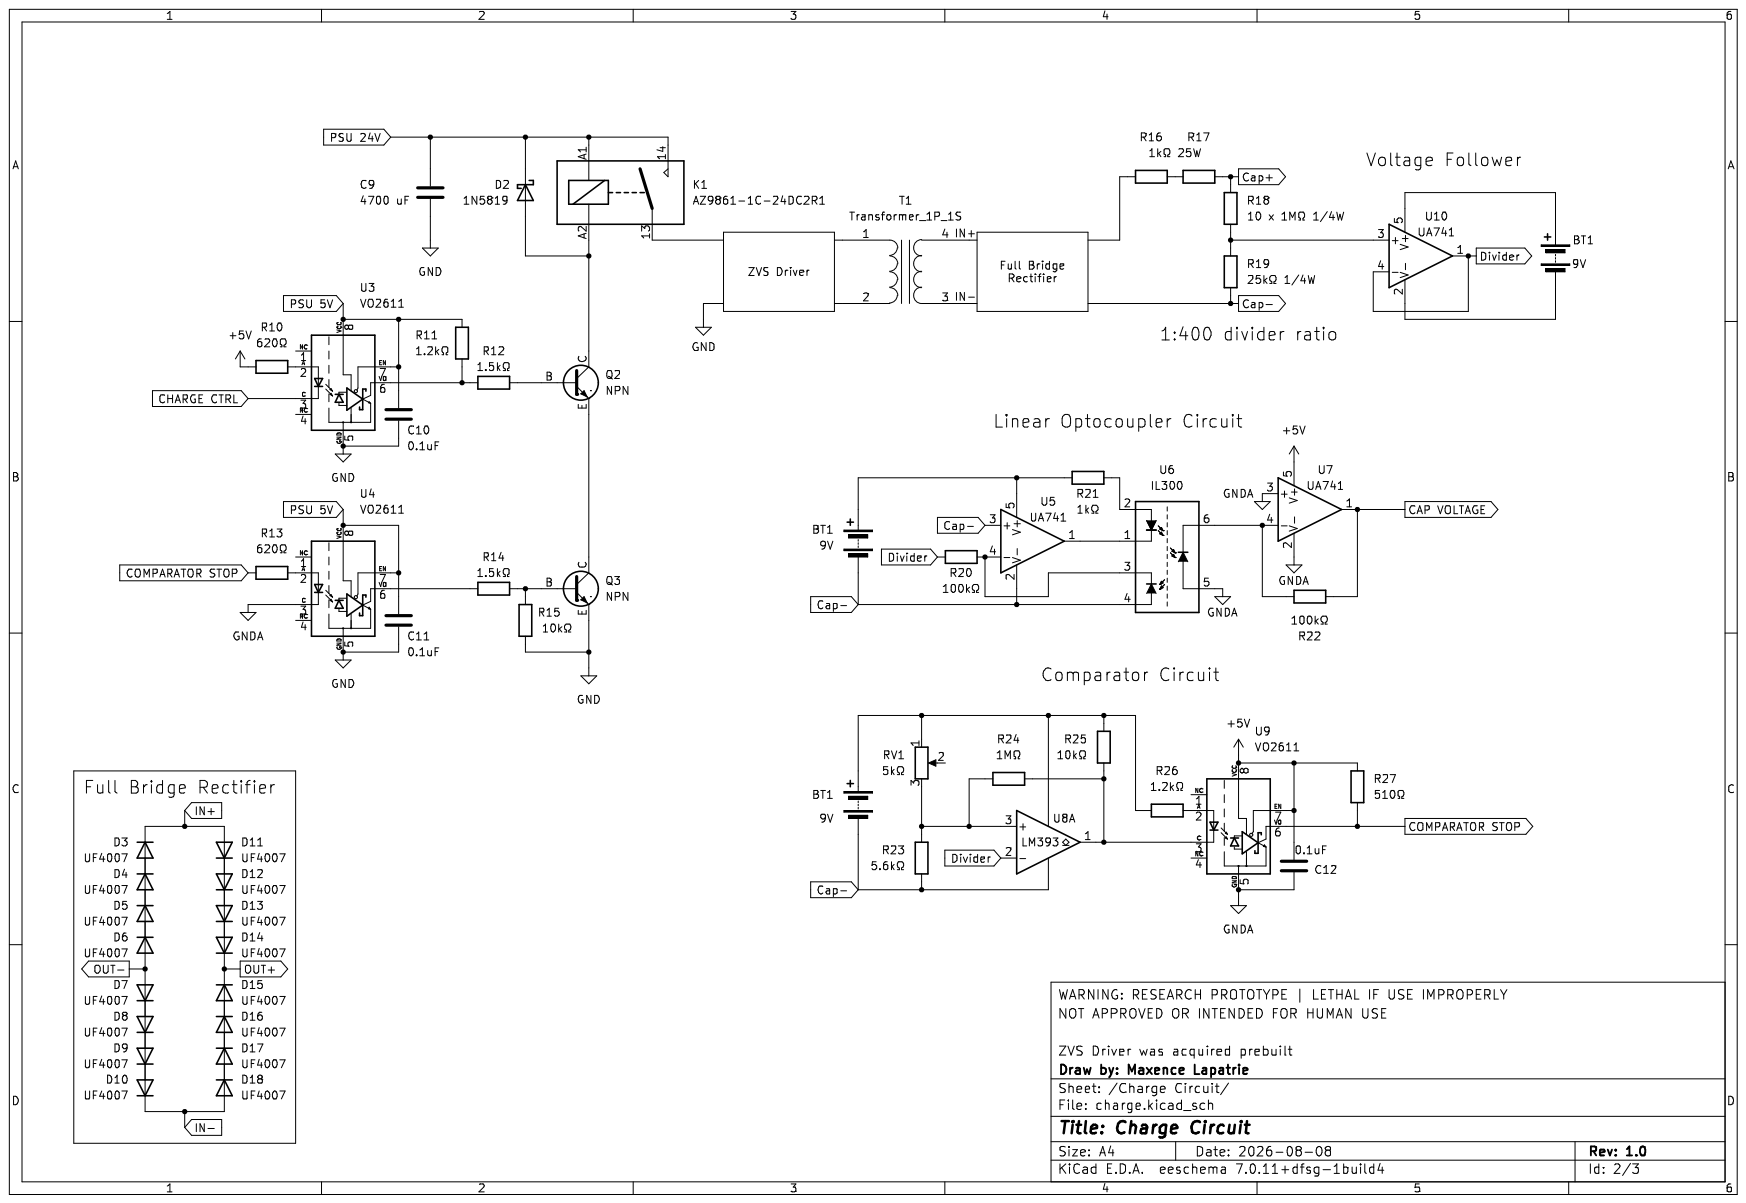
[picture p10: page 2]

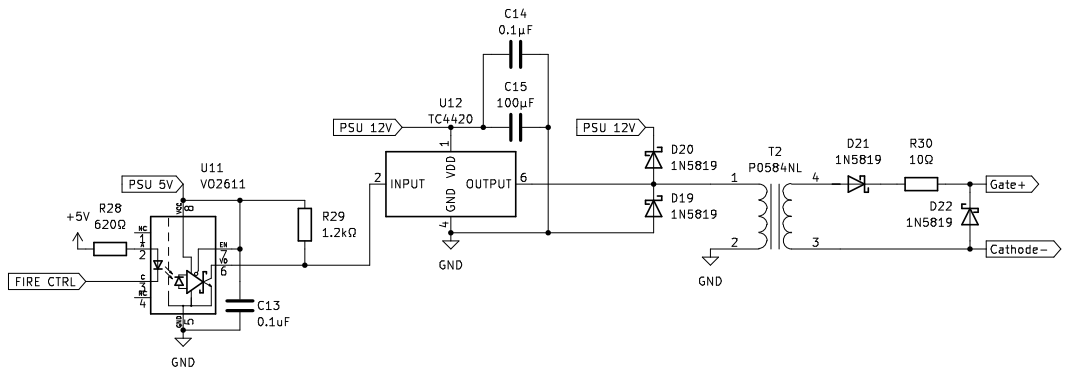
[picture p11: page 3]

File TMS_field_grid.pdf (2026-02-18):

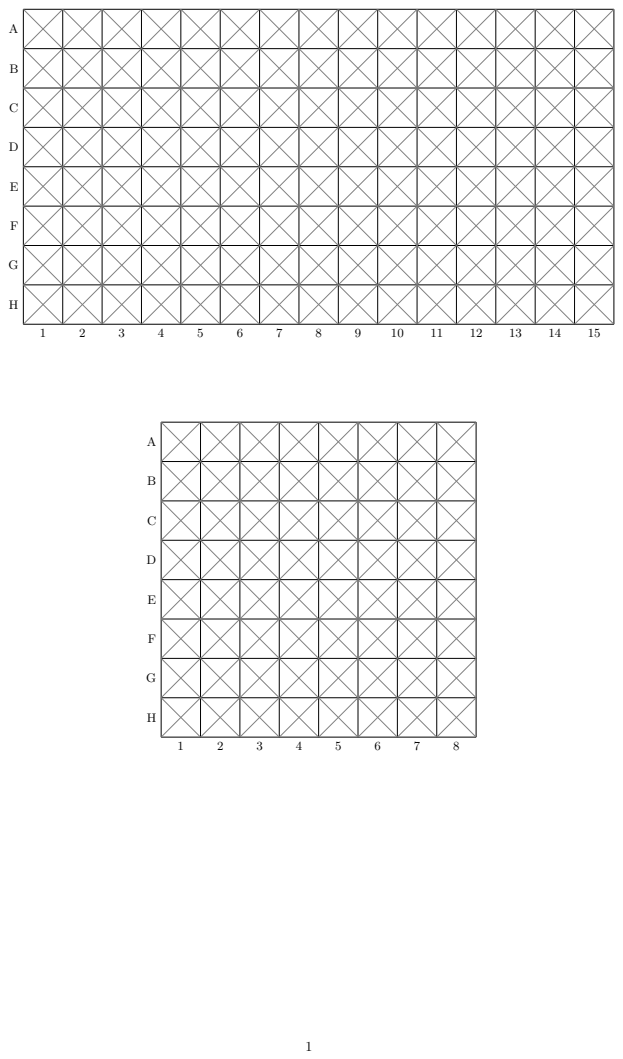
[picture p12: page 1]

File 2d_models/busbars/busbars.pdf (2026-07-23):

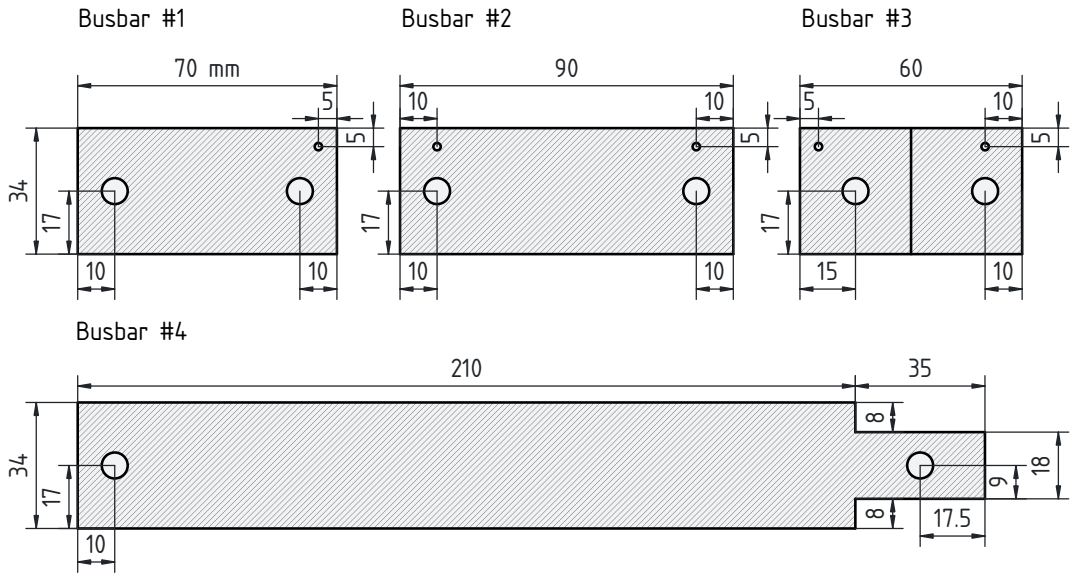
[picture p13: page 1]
Busbar #1; Busbar #2; Busbar #3; 10 10 Busbar #4

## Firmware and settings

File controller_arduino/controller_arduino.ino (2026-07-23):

// SPDX-License-Identifier: MIT
//
// TMS controller firmware for the Arduino UNO R4 Minima (Renesas RA4M1).
//
// This firmware controls high-voltage equipment. It is not a substitute for
// independent hardware interlocks, over-voltage protection, or safe operating
// procedures.

#include <Arduino.h>
#include <string.h>

// BEFORE STARTING -----------------------------------------------------------
// 1. Calculate MAX_ADC from measured values:
//
//       MAX_ADC = round((V_trip / divider_ratio) / V_ref * ADC_FULL_SCALE)
//
//    Example only: round(300 V / 100 / 5 V * 1023) = 614 counts.
// 2. Measure the SCR gate pulse on the assembled controller and adjust
//    FIRE_DELAY_US if the pulse width is not the required value.
// ---------------------------------------------------------------------------
static const uint8_t VCC_PINS[]      = {11, 12, 13};
static const uint8_t COMPARATOR_STOP = 2;
static const uint8_t FIRE_CTRL       = 3;
static const uint8_t CHARGE_CTRL     = 4;
static const uint8_t CAP_VOLTAGE     = A0;

// Comparator input configuration and active state
#define COMP_STOP_PIN_MODE INPUT
#define COMP_STOP_ACTIVE LOW

// ADC configuration. DEFAULT_MAX_ADC in app.py must match MAX_ADC.
static const uint8_t ADC_RESOLUTION_BITS = 10;
static const uint16_t ADC_FULL_SCALE = (1U << ADC_RESOLUTION_BITS) - 1U;
static const uint16_t MAX_ADC = 614;
static_assert(MAX_ADC <= ADC_FULL_SCALE,
              "MAX_ADC must be within the configured ADC range");

// Sampling and telemetry timing.
static const uint32_t SAMPLE_PERIOD_US = 1000;  // 1 kHz ADC sampling.
static const uint32_t TELEM_PERIOD_MS  = 100;   // 10 Hz host telemetry.

// Existing calibrated delay for an approximately 5 us SCR gate pulse.
// Re-measure on the final hardware; GPIO overhead depends on the board/core.
static const uint32_t FIRE_DELAY_US = 3;

// State shared with the comparator interrupt.
volatile bool comp_stop_tripped = false;

// Command-state flags. RESET is required before charging.
bool charge_ok = false;
bool armed = false;
bool charging = false;

uint16_t adc_last = 0;
uint32_t t_last_ms = 0;
uint32_t next_sample_us = 0;
uint32_t next_telem_ms = 0;

// Configure the three outputs that the existing hardware uses as logic-HIGH
// sources. Do not connect loads that exceed the board's GPIO ratings.
static void rails_up() {
  const size_t pin_count = sizeof(VCC_PINS) / sizeof(VCC_PINS[0]);
  for (size_t i = 0; i < pin_count; i++) {
    pinMode(VCC_PINS[i], OUTPUT);
    digitalWrite(VCC_PINS[i], HIGH);
  }
}

// Return command-controlled outputs and state flags to the inactive state.
static void safe_outputs() {
  digitalWrite(CHARGE_CTRL, LOW);
  digitalWrite(FIRE_CTRL, LOW);
  armed = false;
  charge_ok = false;
  charging = false;
}

static void fire_once() {
  // Prevent an interrupt from stretching the calibrated gate pulse.
  noInterrupts();
  digitalWrite(FIRE_CTRL, HIGH);
  delayMicroseconds(FIRE_DELAY_US);
  digitalWrite(FIRE_CTRL, LOW);
  interrupts();
}

static void comp_stop_isr() {
  // Disable charging immediately; loop() performs the non-ISR bookkeeping.
  digitalWrite(CHARGE_CTRL, LOW);
  comp_stop_tripped = true;
}

// Handle the newline-terminated ASCII command protocol used by app.py.
static void handle_command(const char *cmd) {
  if (strcmp(cmd, "RESET") == 0) {
    safe_outputs();
    if (digitalRead(COMPARATOR_STOP) != COMP_STOP_ACTIVE) {
      comp_stop_tripped = false;
      charge_ok = true;
      Serial.println("RESET_OK");
    } else {
      Serial.println("RESET_BLOCKED_HW_TRIP");
    }
  }
  else if (strcmp(cmd, "CHARGE") == 0) {
    if (charge_ok && !armed && !comp_stop_tripped) {
      digitalWrite(CHARGE_CTRL, HIGH);
      charging = true;
      Serial.println("CHARGING");
    } else {
      Serial.println("CHARGE_DENIED");
    }
  }
  else if (strcmp(cmd, "UNCHARGE") == 0) {
    digitalWrite(CHARGE_CTRL, LOW);
    charging = false;
    Serial.println("UNCHARGED");
  }
  else if (strcmp(cmd, "ARM") == 0) {
    digitalWrite(CHARGE_CTRL, LOW);
    charging = false;
    charge_ok = false;
    armed = true;
    Serial.println("ARMED");
  }
  else if (strcmp(cmd, "UNARM") == 0) {
    armed = false;
    Serial.println("UNARMED");
  }
  else if (strcmp(cmd, "FIRE") == 0) {
    if (armed && !charge_ok && !comp_stop_tripped) {
      fire_once();
      armed = false;
      Serial.println("FIRED");
    } else {
      Serial.println("FIRE_DENIED");
    }
  }
  else if (strcmp(cmd, "STATUS") == 0) {
    char buf[96];
    snprintf(buf, sizeof(buf),
             "STATUS ok=%d arm=%d chg=%d hw=%d adc=%u",
             charge_ok, armed, charging, comp_stop_tripped,
             static_cast<unsigned int>(adc_last));
    Serial.println(buf);
  }
  else {
    Serial.print("UNKNOWN:");
    Serial.println(cmd);
  }
}

void setup() {
  pinMode(CHARGE_CTRL, OUTPUT);
  pinMode(FIRE_CTRL, OUTPUT);
  pinMode(COMPARATOR_STOP, COMP_STOP_PIN_MODE);
  pinMode(CAP_VOLTAGE, INPUT);
  analogReadResolution(ADC_RESOLUTION_BITS);

  safe_outputs();
  rails_up();

  // Latch a comparator trip that is already active at startup.
  if (digitalRead(COMPARATOR_STOP) == COMP_STOP_ACTIVE) {
    comp_stop_tripped = true;
  }

  attachInterrupt(digitalPinToInterrupt(COMPARATOR_STOP),
                  comp_stop_isr,
                  COMP_STOP_ACTIVE == HIGH ? RISING : FALLING);

  Serial.begin(115200);
  // Do not wait for a host connection; the controller may run from bench power.
  Serial.println("BOOT");
}

void loop() {
  const uint32_t now_us = micros();
  const uint32_t now_ms = millis();

  // Sample the capacitor-voltage monitor at approximately 1 kHz.
  if ((int32_t)(now_us - next_sample_us) >= 0) {
    next_sample_us = now_us + SAMPLE_PERIOD_US;
    adc_last = analogRead(CAP_VOLTAGE);
    t_last_ms = now_ms;

    if (adc_last > MAX_ADC) {
      digitalWrite(CHARGE_CTRL, LOW);
      if (charge_ok || charging) {
        charge_ok = false;
        charging = false;
        Serial.println("OVERVOLT");
      }
    }
  }

  // Complete handling of a hardware comparator trip latched by the ISR.
  if (comp_stop_tripped) {
    if (charge_ok || charging) {
      digitalWrite(CHARGE_CTRL, LOW);
      charge_ok = false;
      charging = false;
      Serial.println("HW_STOP_TRIPPED");
    }
  }

  // Report controller state to the host at approximately 10 Hz.
  if ((int32_t)(now_ms - next_telem_ms) >= 0) {
    next_telem_ms = now_ms + TELEM_PERIOD_MS;
    char buf[96];
    snprintf(buf, sizeof(buf),
             "T t=%lu adc=%u ok=%d arm=%d chg=%d hw=%d",
             static_cast<unsigned long>(t_last_ms),
             static_cast<unsigned int>(adc_last),
             charge_ok, armed, charging, comp_stop_tripped);
    Serial.println(buf);
  }

  // Read one newline-terminated command. Commands are at most 15 characters.
  if (Serial.available()) {
    static char cmd[16];
    size_t n = Serial.readBytesUntil('\n', cmd, sizeof(cmd) - 1);
    cmd[n] = '\0';
    while (n > 0 && (cmd[n-1] == '\r' || cmd[n-1] == ' ')) cmd[--n] = '\0';
    if (n > 0) handle_command(cmd);
  }
}

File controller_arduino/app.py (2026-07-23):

#!/usr/bin/env python3
# SPDX-License-Identifier: MIT
"""
tms_tui.py - Terminal UI for the TMS controller.

Dependencies:
    pip install "textual>=0.60" pyserial

Run:
    python app.py                    # pick port interactively
    python app.py --port /dev/ttyACM0
    python app.py --port COM3 --divider 100 --max-adc 614
    python app.py --list             # list available serial ports and exit

Keybindings (see footer):
    c   charge / uncharge       a   arm / unarm
    f   FIRE                    r   reset
    s   status query            p   pick port
    d   disconnect              q   quit

Platform notes:
    - Linux/macOS: works in any modern terminal.
    - Windows: works in Windows Terminal, PowerShell, and the newer
      Command Prompt. Use the Cascadia Mono or similar font for block
      characters in the sparkline. WSL is not required.
"""

from __future__ import annotations

import argparse
import queue
import sys
import threading
from collections import deque
from datetime import datetime

import serial
import serial.tools.list_ports

from textual.app import App, ComposeResult
from textual.binding import Binding
from textual.containers import Horizontal, Vertical
from textual.screen import ModalScreen, Screen
from textual.widgets import Footer, Label, ListItem, ListView, RichLog, Static

BAUD = 115200
ADC_FULL_SCALE = 1023
DEFAULT_DIVIDER_RATIO = 100.0
DEFAULT_ADC_REFERENCE_V = 5.0
DEFAULT_MAX_ADC = 614 # must maatch MSAX_ADC in firmware

# Display settings
DEFAULT_AVG_WINDOW = 10
SPARK_BLOCKS = " ▁▂▃▄▅▆▇█"
SPARK_WIDTH = 32
HISTORY_LEN = 100  # 10 s at 10 Hz telemetry


# ======================================================================
# Serial bridge (background read thread, main-thread writes)
# ======================================================================

class SerialBridge:
    def __init__(self) -> None:
        self.ser: serial.Serial | None = None
        self.rx_queue: queue.Queue[str] = queue.Queue()
        self._thread: threading.Thread | None = None
        self._stop = threading.Event()

    def is_open(self) -> bool:
        return self.ser is not None and self.ser.is_open

    def open(self, port_name: str) -> None:
        if self.is_open():
            self.close()
        # Default pyserial config. No DTR/RTS toggling.
        # R4 Minima uses native USB CDC so opening does not reset the MCU.
        self.ser = serial.Serial(port_name, BAUD, timeout=0.1)
        self._stop.clear()
        self._thread = threading.Thread(target=self._read_loop, daemon=True)
        self._thread.start()

    def close(self) -> None:
        self._stop.set()
        t = self._thread
        self._thread = None
        if t and t.is_alive():
            t.join(timeout=0.5)
        if self.ser:
            try:
                self.ser.close()
            except Exception:
                pass
            self.ser = None

    def send(self, cmd: str) -> None:
        if not self.is_open():
            return
        try:
            self.ser.write((cmd + "\n").encode("ascii"))
        except Exception as e:
            self.rx_queue.put(f"__WRITE_ERROR__:{e}")

    def _read_loop(self) -> None:
        buf = ""
        while not self._stop.is_set():
            try:
                data = self.ser.read(256) if self.ser else b""
            except Exception as e:
                self.rx_queue.put(f"__READ_ERROR__:{e}")
                return
            if not data:
                continue
            buf += data.decode("ascii", errors="replace")
            while True:
                nl = buf.find("\n")
                if nl < 0:
                    break
                line = buf[:nl].rstrip("\r")
                buf = buf[nl + 1:]
                if line:
                    self.rx_queue.put(line)


# ======================================================================
# Helpers
# ======================================================================

def parse_kv(s: str) -> dict[str, str]:
    out: dict[str, str] = {}
    for tok in s.split():
        if "=" in tok:
            k, v = tok.split("=", 1)
            out[k] = v
    return out


def sparkline(values: list[int], width: int, vmax: int) -> str:
    if width <= 0:
        return ""
    if not values or vmax <= 0:
        return " " * width
    n = len(values)
    if n >= width:
        step = n / width
        chunks = [values[int(i * step):int((i + 1) * step)] for i in range(width)]
    else:
        chunks = [[] for _ in range(width - n)] + [[v] for v in values]
    out = []
    top = len(SPARK_BLOCKS) - 1
    for c in chunks:
        if not c:
            out.append(" ")
            continue
        avg = sum(c) / len(c)
        ratio = min(1.0, avg / vmax)
        out.append(SPARK_BLOCKS[int(ratio * top)])
    return "".join(out)


def ts() -> str:
    now = datetime.now()
    return now.strftime("%H:%M:%S.") + f"{now.microsecond // 1000:03d}"


# ======================================================================
# Port picker
# ======================================================================
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

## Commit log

2025-12-26 Moved charge
2025-12-26 Moved discharge
    [discharge.sch]
2025-12-27 Discharge and RLC circuit helpers
2026-01-13 Added gate driver
2026-01-13 gate driver
2026-01-17 Added kicad files
    [charge.kicad_sch, discharge.kicad_sch, gate_driver.kicad_sch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]
2026-01-21 Kicad files
    [charge.kicad_sch, gate_driver.kicad_sch, tms.kicad_sch]
2026-01-21 Removed data files
    [discharge.sch]
2026-01-24 Schematic fixes after real life tests
    [charge.kicad_sch, gate_driver.kicad_sch, tms.kicad_sch]
2026-01-28 Linear Optocoupler schematic (non function rn)
2026-01-28 Cleaned schematic and fixed LV wiring
2026-01-29 Fixed optocoupler output logic
    [charge.kicad_sch, gate_driver.kicad_sch]
2026-01-29 Fixed the linear optocoupler schematic
    [charge.kicad_sch]
2026-01-30 Fixed TMS schematic
    [charge.kicad_sch, gate_driver.kicad_sch, tms.kicad_sch]
2026-02-03 controller arduino code added
2026-02-03 Update README with Arduino controller information
    Added section for Arduino controller code and its functions.
2026-02-05 Coil winder 3d files
    [coil_winder(Neurotech).iges, coilwinder2.obj]
2026-02-05 Added stripped winder
    [coil_winder.iges, coil_winder.obj, stripped_winder.obj]
2026-02-05 Removed duplicate
    [coilwinder2.obj]
2026-02-06 Updated schematic pdf
2026-02-19 Modified visualization code
    [20260217_TMS_Efield_VoltagePulse.xlsx, SDS00001.CSV, SDS00002.CSV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]
2026-03-02 Data collection script and db/dt heatmap
2026-04-19 Adding freecad
    [TMS_holder-Body.stl, TMS_holder.FCStd, sensing_cross-Body.stl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]
2026-04-22 Schematic changes
    [charge.kicad_sch, gate_driver.kicad_sch, tms.kicad_sch]
2026-05-11 Added auto arm after capture
2026-05-17 Organizational changes
    [TMS_holder-Body.stl, TMS_holder.FCStd, charge.kicad_sch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]
2026-05-25 Fixed optocoupler wiring bug
    [charge.kicad_sch, gate_driver.kicad_sch]
2026-06-12 Small changes
    [sensing_guide-Body.stl, sensing_guide.FCStd, sensing_pick-Body.stl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]
2026-06-14 Pickup cylinder
    [pickup_cylinder.stl, pickup_cylinder.stl.FCStd, pickup_winding_cylinder.stl]
2026-07-23 FreeCAD files for winding instructions and busbar dimensions.
    [busbars.FCStd, coil_windings.FCStd]
2026-07-23 Fixed 3d models and redid coil winder
    [coil_winder.FCStd, coil_winder.iges, coil_winder.obj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]
2026-07-23 Fixed and polished app.py and controller_arduino.ino
    [app.py, controller_arduino.ino]
2026-07-23 Small schematic fixes
    [charge.kicad_sch, gate_driver.kicad_sch, tms.kicad_sch]
2026-07-24 Added waveforms for recreating computations
    [waveform_A10_1.csv, waveform_A10_2.csv, waveform_A10_3.csv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]
2026-07-24 Small changes.
    [TMS_holder-Body.stl, TMS_holder.FCStd]
2026-07-24 Add licensing notice for project materials
    Added licensing information for hardware and software components.
2026-07-24 Add Creative Commons Attribution 4.0 License
    This file contains the full text of the Creative Commons Attribution 4.0 International Public License, outlining the terms and conditions for using the licensed material.
2026-07-24 Update licensing information in README.md
    Added CC-BY-4.0 licensing information for project-authored materials.
2026-07-24 Added capacitor waveform figure
2026-07-27 Schematic update
    [charge.kicad_sch]
2026-07-27 Added BOM
    [TMS US component list.ods]
2026-08-08 Updated schematics
2026-08-09 Updated schematic
